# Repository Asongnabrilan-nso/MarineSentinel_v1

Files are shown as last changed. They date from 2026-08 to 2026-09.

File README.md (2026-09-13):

# 🌊 MarineSentinel

**A ~$300 floating AI sentinel that watches a river or coastline for plastic
pollution around the clock, and logs water quality — built on a single
Arduino UNO Q.**

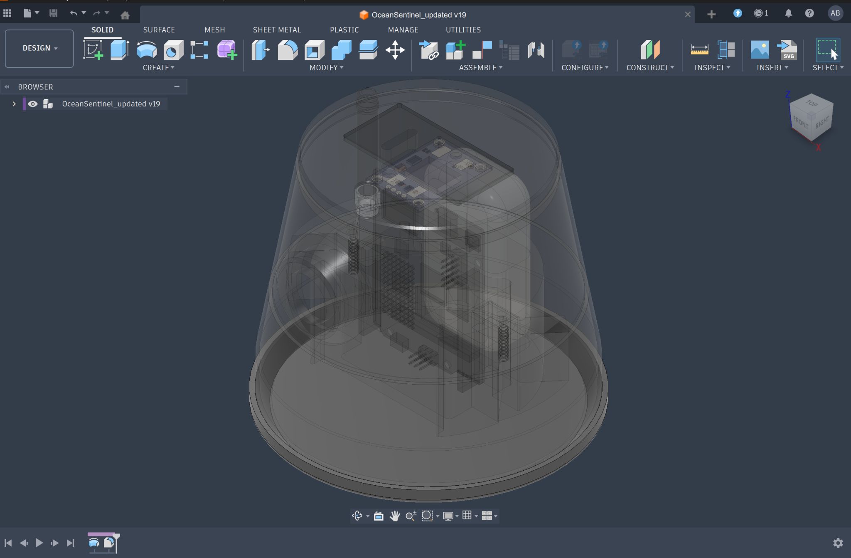
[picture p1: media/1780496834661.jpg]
MarineSentinel buoy — Fusion 360 cutaway render showing the sealed electronics stack inside the capsule


📖 Full project write-up (story + build photos):
[hackster.io/abrilannso/marinesentinel-60f927](https://www.hackster.io/abrilannso/marinesentinel-60f927)
&nbsp;·&nbsp; 🔧 Technical deep-dive:
[`firmware/README.md`](firmware/README.md)
&nbsp;·&nbsp; 👤 Built by
[Asongna Brilan Nso Nkengafac](https://www.hackster.io/abrilannso)

---

## Contents

1. [Overview](#overview)
2. [At a glance](#at-a-glance)
3. [How it works](#how-it-works)
4. [Bill of materials](#bill-of-materials)
5. [Build guide](#build-guide)
6. [Repository layout](#repository-layout)
7. [Troubleshooting](#troubleshooting)
8. [Conclusion](#conclusion)
9. [Credits](#credits)

---

## Overview

MarineSentinel started on a visit to Limbe Down Beach (Cameroon), watching
plastic wash in through the drains and inlets that feed the ocean — water
that local fishing communities depend on. Almost nobody measures any of this
continuously: pollution is recorded, if at all, by someone travelling to a
site to take one photo or one sample. A commercial multi-parameter water
sonde costs US$25,000–40,000, so no local municipality instruments a river,
and "we have no numbers" becomes the reason cleanup funding proposals fail.

MarineSentinel is a small sealed buoy that floats on the water and watches
it for you, day and night:

- A **camera + on-device AI model** learns what floating plastic and debris
  look like and flags it when it sees it.
- Onboard sensors continuously measure **turbidity**, **water temperature**,
  and the buoy's own **tilt/motion** from the waves.
- A **GPS fix** locates every reading and every alert.
- Everything is served live from a **web dashboard the buoy hosts itself**
  over WiFi — open it on a phone at the water's edge, no internet required.

It doesn't scoop up trash — it's the sensor layer for someone else's
cleanup: it tells a crew *where* and *when* debris is flowing, and warns
people who depend on the water the moment a reading looks wrong. Every part
is buyable locally within 48 hours, so a local workshop can rebuild or
repair it without waiting on an import.

## At a glance

| | |
|---|---|
| **Board** | Arduino UNO Q (STM32 MCU + Linux MPU on one board) |
| **Cost** | ~US$300 all-in, nothing imported |
| **Senses** | Turbidity · water temperature · tilt/orientation (IMU) · GPS |
| **AI** | On-camera debris detection — built-in YOLO-X or a custom Edge Impulse model |
| **Output** | Self-hosted live web dashboard (`http://<board-ip>:7000`), no internet needed |
| **Enclosure** | 3D-printed PETG, 5 snap-together parts, solar-trickle powered |

**Status — bench-proven and water-tested, end to end:**
- ✅ Live camera feed with on-device debris detection (YOLO-X / custom Edge Impulse model)
- ✅ Turbidity + temperature sampled every 2 s, with alert thresholds
- ✅ IMU-driven 3D tilt view at 10 Hz, with a capsize/listing alert
- ✅ GPS fix pushed to the dashboard at 1 Hz
- ✅ Sensor/orientation/detection history logged to on-device InfluxDB
- ✅ Camera and IMU startup are retry-safe — a missing sensor fails open instead of crashing the app

## How it works

The Arduino UNO Q carries two processors on one board, and MarineSentinel
gives each the job it's built for, passing messages between them over
[Arduino App Lab](https://docs.arduino.cc/software/app-lab/)'s **Router
Bridge**:

```
┌──────────────────────────────┐                     ┌──────────────────────────────────┐
│  MCU (Zephyr sketch)         │  Router Bridge:      │  MPU (Python / web_ui)            │
│  sketch/sketch.ino           │  sensor_data (2s)    │  python/main.py                    │
│                               │  imu_data (100ms)     │                                    │
│  A0      ── turbidity sensor │  gps_data (1s)          │  ├─ sensors.py (state + alerts)  │
│  D4      ── DS18B20 (1-Wire) │ ────────────────────────▶│  ├─ data_store.py (InfluxDB)     │
│  QWIIC   ── MPU6050 IMU      │                          │  ├─ assets/ (static HTML/JS —    │
│            (I2C4 = Wire1)    │  ◀────────────────────  │  │   CSS-3D capsule, no CDN)      │
│  D20/D21 ── GPS (Serial3)    │  set_alert(bool)      │  └─ VideoObjectDetection             │
│  LED3    ── alert indicator  │                     │        (YOLO-X / custom Edge Impulse) │
└──────────────────────────────┘                     └──────────────────┬─────────────────────┘
                                                                          │ :7000 (Socket.IO)
                                                                          ▼
                                                           Browser dashboard (LAN) — camera pane
                                                           and orientation view refresh at 10 Hz,
                                                           independent of the rest of the page
```

1. **The real-time microcontroller reads the world.** The sketch samples
   turbidity and a DS18B20 water-temperature probe every 2 s, fuses the
   MPU6050 accelerometer + gyroscope into roll/pitch/yaw at 10 Hz, parses
   GPS NMEA sentences continuously, and drives the onboard RGB LED
   green/red as a local alarm — all independent of whether Python is even
   listening.
2. **The Linux processor runs the AI and the dashboard.** An always-on
   Python process (`arduino:web_ui`) runs object detection on the USB
   camera feed, converts raw sensor values to engineering units, evaluates
   alert thresholds (including a capsize/listing check on tilt), writes
   history to an on-device InfluxDB, and serves a static dashboard.
3. **The two halves stay in sync over the bridge.** The sketch fires
   `sensor_data`, `imu_data`, and `gps_data` up to Python; Python sends
   `set_alert` back down to drive the LED.

Three App Lab bricks do the heavy lifting (declared in
[`firmware/app.yaml`](firmware/app.yaml)):

| Brick | Purpose |
|---|---|
| `arduino:video_object_detection` | Object detection (built-in YOLO-X, or a custom Edge Impulse export) on the USB camera stream |
| `arduino:web_ui` | Always-on Python process + the Socket.IO dashboard on port `7000` |
| `arduino:dbstorage_tsstore` | InfluxDB-backed time-series storage for sensor/orientation history |

<details>
<summary><strong>Why this needs two processors, and why <code>web_ui</code> instead of Streamlit</strong> (click to expand)</summary>

- **Two processors, one board.** The real-time MCU owns the sensors and
  electronics; the Linux side only carries the vision model and dashboard —
  no separate SBC + microcontroller pair to wire together.
- **App Lab bricks instead of hand-rolled services.** The camera model
  runner, the dashboard, the time-series database, and start-on-boot all
  arrive as declared components in `app.yaml`.
- **`web_ui`, not Streamlit.** Streamlit only executes app code the first
  time a browser opens the dashboard — on an unattended buoy deployment
  where nobody opens the dashboard, the Bridge providers, camera/AI
  detector, and InfluxDB storage would never start at all. `web_ui` is a
  plain always-on process: everything starts the instant the app boots,
  dashboard or not.
- **The 3D capsule tilt indicator** is drawn with plain CSS 3D transforms —
  no Three.js, no CDN — so it still renders for a browser that can only
  reach the buoy itself, out on the water with no path to anywhere else.
- **The repo mirrors the device.** [`firmware/`](firmware) is exactly the
  on-device app layout — what you clone is what runs.

See [`firmware/README.md`](firmware/README.md) for the full changelog and
the non-obvious bugs this surfaced along the way (I²C bus selection on the
QWIIC connector, Bridge/`App.run()` ordering, etc.).

</details>

## Bill of materials

Everything beyond the UNO Q itself came to roughly **157,506 XAF (~US$260)**,
sourced entirely locally — the whole build lands under $300 with no
import/customs step on the critical path.

| Component | Notes |
|---|---|
| Arduino UNO Q | the board — MPU + MCU |
| USB webcam (e.g. Logitech HD Pro) | debris-detection camera |
| MPU6050 6-DOF IMU (e.g. DFRobot breakout) | mounts on the QWIIC connector |
| DS18B20 waterproof temperature probe | 1-Wire, e.g. DFRobot Gravity |
| GPS receiver (e.g. Adafruit Ultimate GPS Breakout) | NMEA over `Serial3` |
| Turbidity sensor, phototransistor output | e.g. SEN0189-class module |
| Solar panel, 2.5 W + buck converter | trickle-charges the buoy in the field |
| Li-Ion battery, 1000 mAh | onboard power |
| PETG filament | for the 3D-printed enclosure |
| 2× M3 screws | the only fasteners — the enclosure snaps together |

## Build guide

Follow these in order. Steps 1–4 are mechanical/electrical and can be done
without the board powered on; steps 5–8 bring the firmware up.

### Step 1 — 3D-print the enclosure

Print the five parts from [`mechanical/stl/`](mechanical/stl) in PETG (STEP
source: `mechanical/stl/MarineSentinel.step`). They snap together with just
2× M3 screws — no glue.

| Part | Holds |
|---|---|
| **Buoy Cover** | solar panel, GPS antenna, charging/power electronics |
| **Buoy Mid Body** | the camera, for live footage |
| **Buoy Bottom** | the IMU and water-facing sensors |
| **Buoy Floating Base** | flotation (polythene foam) |
| **Electronics Enclosure** | the UNO Q, battery, and wiring |

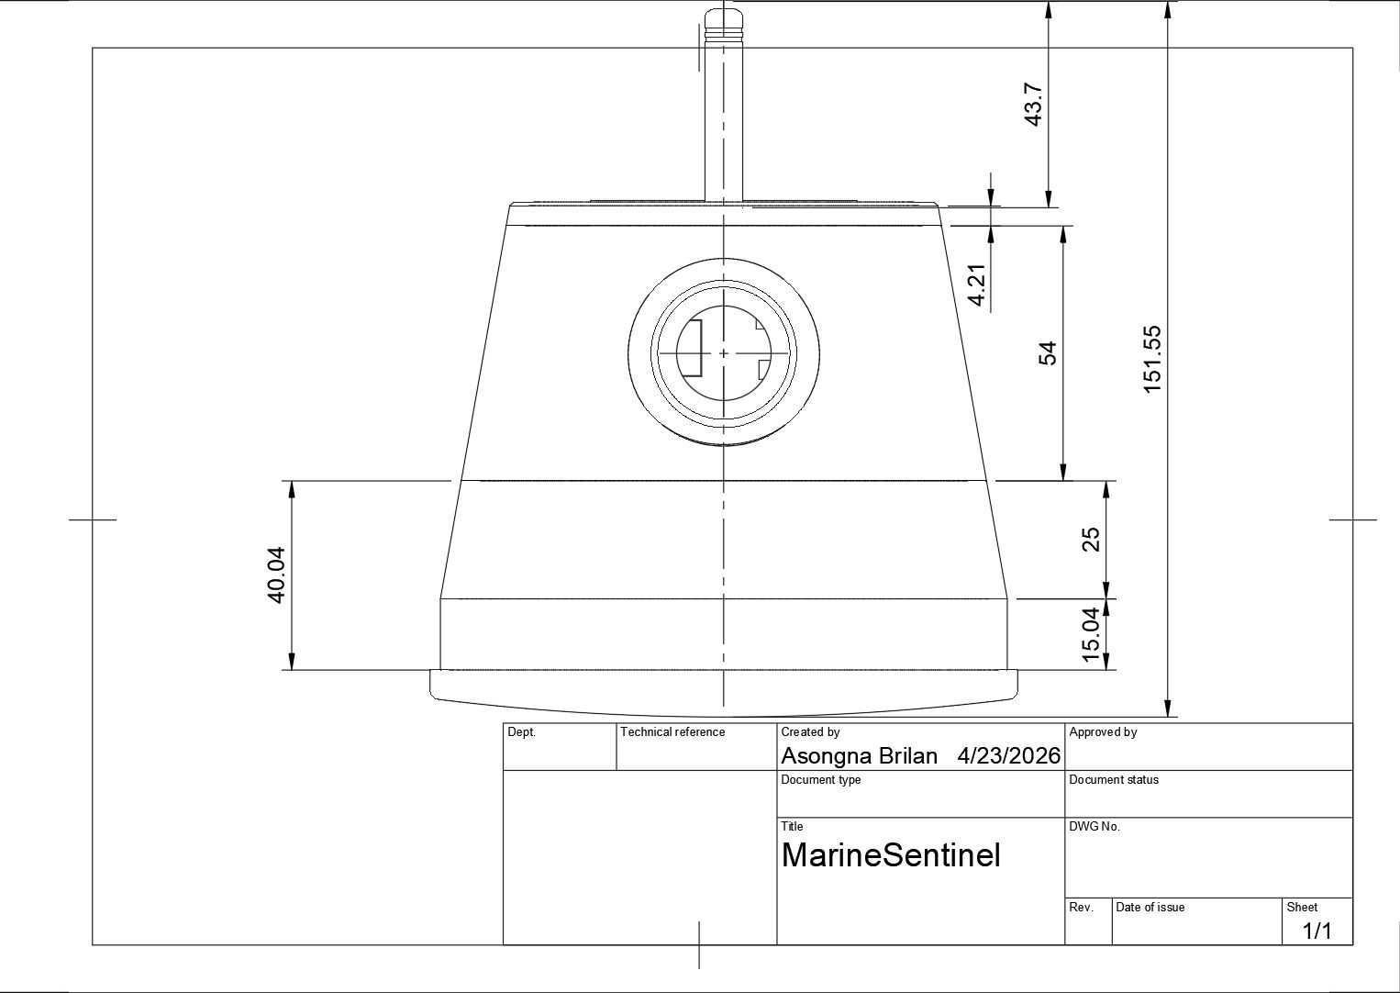
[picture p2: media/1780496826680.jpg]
Dimensioned CAD drawing of the buoy body


### Step 2 — Wire power and solar

Mount the 2.5 W solar panel and GPS antenna on the **Buoy Cover**'s top
side; mount the charging circuit, buck converter, and battery on its
underside.

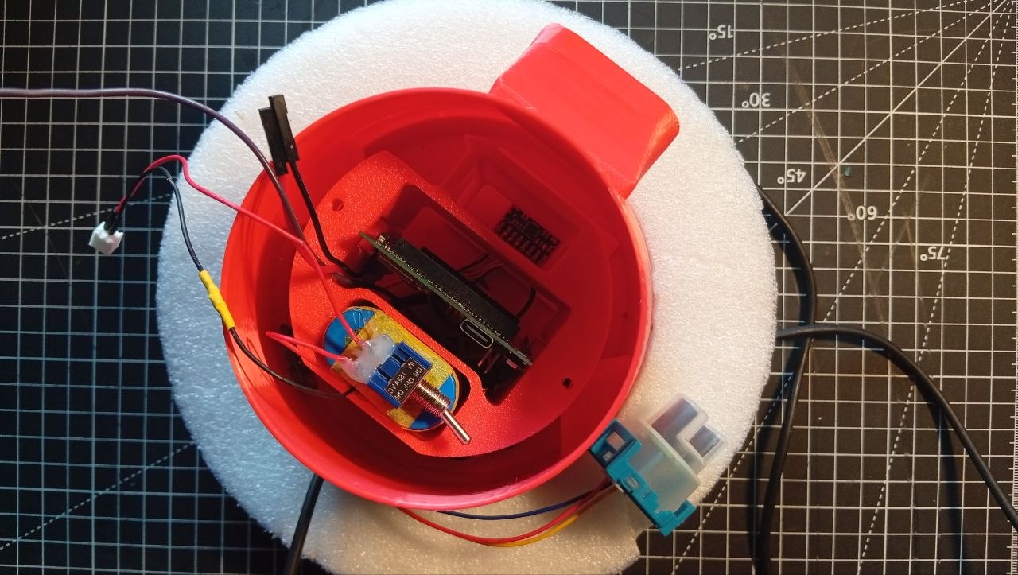
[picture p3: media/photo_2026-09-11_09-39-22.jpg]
Power and GPS electronics mounted in the buoy cover


### Step 3 — Mount electronics and sensor modules

1. Place the turbidity + temperature sensor module in the **Buoy Bottom**.
2. Seat the 7.4 V battery pack in the **Electronics Enclosure**.
3. Slide the UNO Q onto the guide rail, then close the enclosure over it.

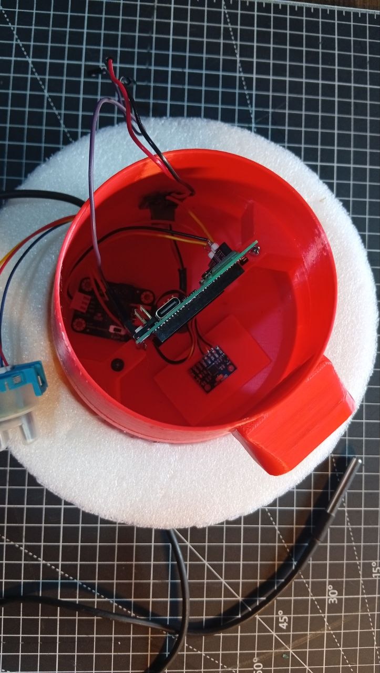
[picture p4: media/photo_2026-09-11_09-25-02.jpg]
Sensor module mounted in the buoy bottom


### Step 4 — Final assembly

Snap the Buoy Bottom, Mid Body, Cover, and Electronics Enclosure together
onto the Floating Base and drive in the two M3 screws. Double-check every
sensor cable is routed before closing the capsule — it's sealed once
assembled.

### Step 5 — (Optional) train a custom debris model in Edge Impulse

The built-in `arduino:video_object_detection` brick ships a general-purpose
YOLO-X model that already recognizes common floating objects. For
debris-specific detection instead:

1. Create a project on [Edge Impulse Studio](https://www.edgeimpulse.com/).
2. Collect and label photos (e.g. plastic bags, plastic bottles, open ocean
   water).
3. Train an object-detection model and export it via Edge Impulse's **App
   Lab export** — no manual model files or SDK calls to manage.

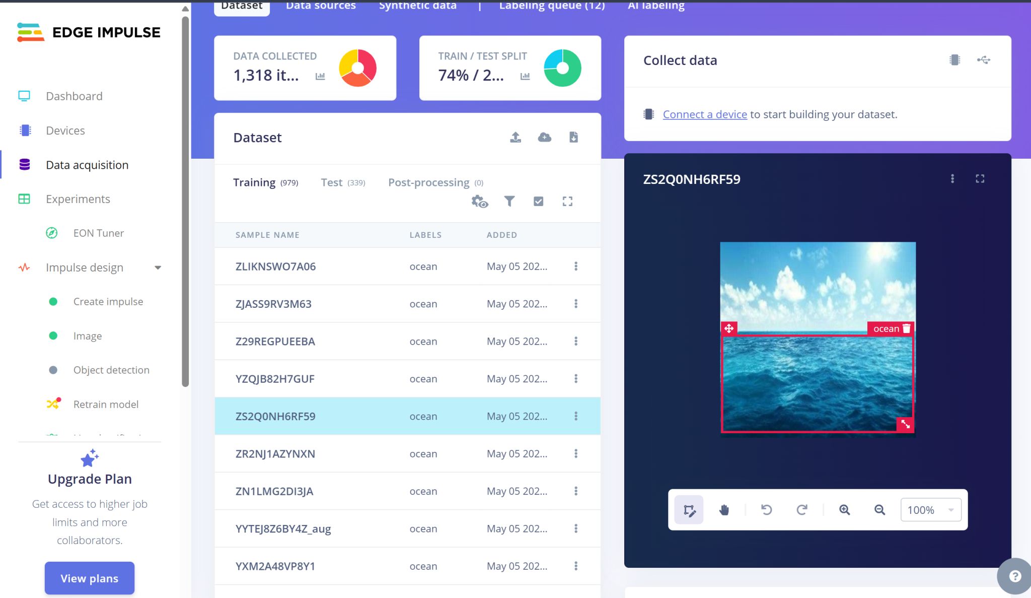
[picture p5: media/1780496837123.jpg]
Edge Impulse Studio dataset — labeled ocean water samples
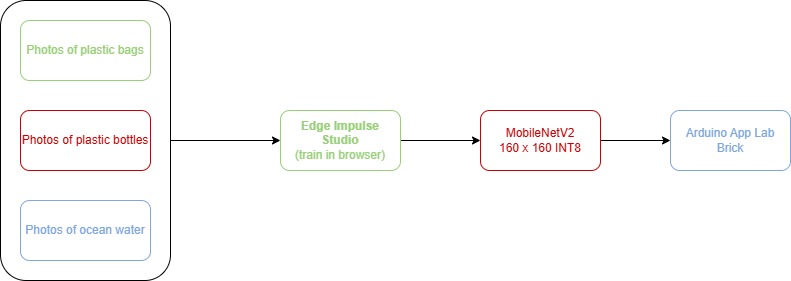
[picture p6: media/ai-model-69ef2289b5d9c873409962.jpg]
Custom model training pipeline: labeled photos through Edge Impulse Studio to a MobileNetV2 model deployed as an App Lab brick
 

### Step 6 — Install Arduino App Lab and set up the board

1. Install [Arduino App Lab](https://www.arduino.cc/en/software/).
2. Connect the UNO Q with a USB-C cable.
3. On first connection, App Lab prompts you to name the board, set a
   password, and join it to your WiFi (or a local hotspot) — do that.

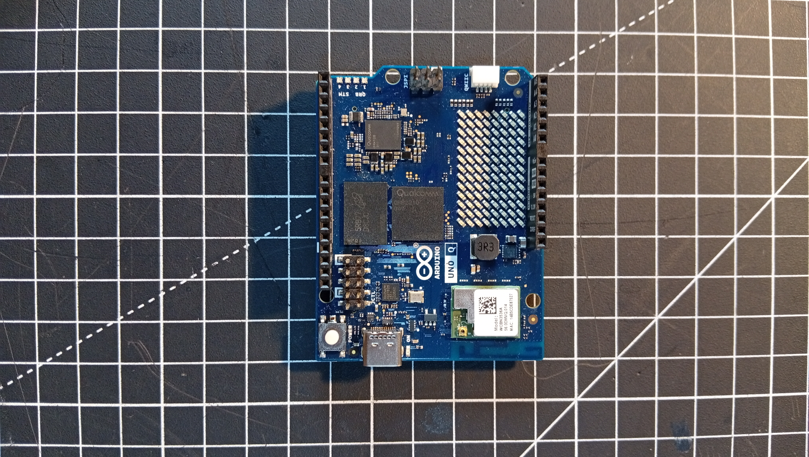
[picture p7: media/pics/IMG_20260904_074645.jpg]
Arduino UNO Q board
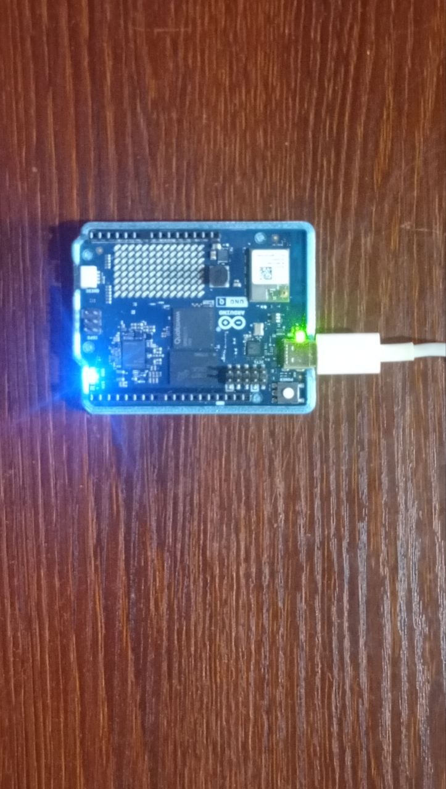
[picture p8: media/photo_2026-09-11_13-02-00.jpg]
Arduino UNO Q powered on via USB-C
 

### Step 7 — Clone and load the app

From the board's shell (SSH, or App Lab's built-in terminal) for full
control over the files:

```bash
git clone https://github.com/Asongnabrilan-nso/MarineSentinel_v1.git ~/ArduinoApps/MarineSentinel_v1
```

Open `~/ArduinoApps/MarineSentinel_v1/firmware` as the app in App Lab (or
just use the CLI directly — see Step 8).

### Step 8 — Point `app.yaml` at your model, then run it

If you trained a custom model in Step 5, register it and point the app at
it — otherwise skip straight to `app start` and the built-in YOLO-X model
is used:

```bash
arduino-app-cli model list          # confirm your Edge Impulse import shows up
```

```yaml
# firmware/app.yaml
bricks:
  - arduino:video_object_detection:
      model: ei-model-XXXXXX-N      # the ID from `model list`
```

Then build, flash, and launch everything in one command:

```bash
arduino-app-cli app start ~/ArduinoApps/MarineSentinel_v1/firmware
```

This compiles and flashes `sketch/sketch.ino` to the MCU, builds the Python
environment, and starts the dashboard + video-detection runner + InfluxDB.
First start takes a few minutes while dependencies download.

> ⚠️ `app start` **stops whatever app is currently running** on the board —
> only one App runs at a time.

Make sure the USB camera is plugged in (use a USB-C hub if the board's
port is occupied) before starting.

### Step 9 — Open the dashboard

From any device on the same WiFi/LAN as the board:

```
http://<board-ip>:7000
```

You should see live turbidity/temperature tiles, the orientation capsule
tracking the buoy's tilt, a live annotated camera feed, and a debris
detection log.

**Everyday commands, once it's running:**

```bash
arduino-app-cli app restart ~/ArduinoApps/MarineSentinel_v1/firmware      # apply code changes
arduino-app-cli app logs    ~/ArduinoApps/MarineSentinel_v1/firmware --follow   # Python logs
arduino-app-cli monitor                                                   # MCU Serial.print()
arduino-app-cli app stop    ~/ArduinoApps/MarineSentinel_v1/firmware
```

## Repository layout

```
MarineSentinel_v1/
├── firmware/               # the Arduino App — this is what you clone onto the board
│   ├── app.yaml             # manifest + brick declarations
│   ├── python/                # main.py, sensors.py, data_store.py
│   ├── sketch/                  # sketch.ino, sketch.yaml
│   ├── assets/                    # static dashboard (HTML/JS/CSS, Socket.IO)
│   └── README.md                    # full technical write-up, wiring, troubleshooting
├── mechanical/              # Fusion 360 STEP + STL files for the enclosure
├── media/                   # build/CAD/dashboard photos used in this README
└── marinesentinel_spec.json # project spec (requirements, BOM, timeline)
```

## Troubleshooting

Camera not found, IMU not detected, GPS stuck without a fix, dashboard
feeling stuck — the full troubleshooting table, wiring reference, and the
reasoning behind each fix live in
[`firmware/README.md` → §3.4 Troubleshooting](firmware/README.md#34-troubleshooting).

That file is also the place to look for:
- [Adding more sensors](firmware/README.md#5-adding-more-sensors) (worked
  example, e.g. a pH sensor)
- [Loading a different Edge AI model](firmware/README.md#4-loading-a-different-edge-ai-model-edge-impulse)
- The dated [changelog](firmware/README.md#7-changelog) of what changed and
  why

## Conclusion

MarineSentinel started from a simple frustration: the water that needed
watching the most was the water nobody could afford to watch. A
US$25,000–40,000 sonde was never going to sit in a river in Cameroon, so the
only way to get numbers was to build something that could.

What's in this repo is a buoy built almost entirely from parts on a local
bench — turbidity, temperature, tilt, GPS, and a camera with an AI model
that already knows what a plastic bottle looks like — running on one board,
reporting itself over a dashboard with no internet needed. It isn't a
finished monitoring network. It's proof that a $300, locally-sourced
instrument can do the job a $30,000 imported one was priced to do, and that
someone at the water's edge can read it on their phone.

It's also not a cleanup tool, and it doesn't pretend to be. MarineSentinel's
job stops at telling someone *where* the debris is and *when* the water
turns bad — the cleanup crew, the health warning, the funding case built on
real data instead of a single photo, that's for whoever picks up what it
reports.

**What's next:**

- **Longer deployments** — the current build is bench- and water-tested in
  short runs; the real test is weeks on the water unattended.
- **A magnetometer** — to fix the yaw drift (see
  [`firmware/README.md` §2.6](firmware/README.md#26-yaw-has-no-accelerometer-equivalent-correction--it-will-drift))
  and give the buoy a real compass heading, not just relative orientation.
- **More water-quality sensors** (pH, dissolved solids) — the sensor
  pipeline is built to make this a small, worked-example change, not a
  redesign (see
  [`firmware/README.md` §5](firmware/README.md#5-adding-more-sensors)).
- **More than one buoy** — a single sentinel gives you a point reading; a
  handful along a coastline gives you a map of where the pollution is
  actually coming from.

Every file, every model, every STL is in this repo. If the water near you
has the same problem — no data because no one can afford to collect it —
this is built to be cloned, not just read about.

## Credits

Built by [Asongna Brilan Nso Nkengafac](https://www.hackster.io/abrilannso).
Full project story, build log, and step-by-step assembly photos:
[hackster.io/abrilannso/marinesentinel-60f927](https://www.hackster.io/abrilannso/marinesentinel-60f927).

Source is licensed Mozilla Public License 2.0 (see SPDX headers in
`firmware/python/` and `firmware/sketch/`).

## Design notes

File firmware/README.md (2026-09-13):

# 🌊 MarineSentinel

Marine water quality monitoring for the Arduino UNO Q, combining real-time
sensor fusion (turbidity + temperature + orientation) on the MCU with Edge AI
debris detection and a live web dashboard on the MPU.

- **MCU (sketch)** — samples a turbidity sensor and a DS18B20 temperature
  probe every 2 s, fuses accel+gyro from an MPU6050 (QWIIC/I2C) into
  roll/pitch/yaw at 10 Hz, parses GPS NMEA sentences continuously and
  reports a fix at 1 Hz, streams all of it to the MPU over the Router
  Bridge, and drives an onboard RGB LED (green/red) as a local alert
  indicator.
- **MPU (Python)** — receives sensor + orientation + GPS readings, converts
  them to engineering units, evaluates alert thresholds (including a
  capsize/tilt check), stores history in InfluxDB, runs YOLO-X (or a custom
  Edge Impulse) object detection on a USB camera feed to spot floating
  debris, and publishes everything — including a live 3D capsule
  orientation view — to a static HTML/JS dashboard served over Socket.IO on
  port `7000`.

---

## 1. Architecture

```
┌──────────────────────────────┐                     ┌──────────────────────────────────┐
│  MCU (Zephyr sketch)         │  Router Bridge:      │  MPU (Python / web_ui)            │
│  sketch/sketch.ino           │  sensor_data (2s)    │  python/main.py                    │
│                               │  imu_data (100ms)     │                                    │
│  A0      ── turbidity sensor │  gps_data (1s)          │  ├─ sensors.py (state + alerts)  │
│  D4      ── DS18B20 (1-Wire) │ ────────────────────────▶│  ├─ data_store.py (InfluxDB)     │
│  QWIIC   ── MPU6050 IMU      │                          │  ├─ assets/ (static HTML/JS —    │
│            (I2C4 = Wire1)    │  ◀────────────────────  │  │   CSS-3D capsule, no CDN)      │
│  D20/D21 ── GPS (Serial3)    │  set_alert(bool)      │  └─ VideoObjectDetection             │
│  LED3    ── alert indicator  │                     │        (YOLO-X / custom Edge Impulse) │
└──────────────────────────────┘                     └──────────────────┬─────────────────────┘
                                                                          │ :7000 (Socket.IO)
                                                                          ▼
                                                           Browser dashboard (LAN) — camera pane
                                                           and orientation view refresh at 10 Hz,
                                                           independent of the rest of the page
```

Bricks used (`app.yaml`):

| Brick | Purpose |
|---|---|
| `arduino:video_object_detection` | Runs the object-detection model (built-in YOLO-X, or a custom Edge Impulse export) against the USB camera stream |
| `arduino:web_ui` | Hosts the always-on Python process and the static Socket.IO dashboard on port 7000 |
| `arduino:dbstorage_tsstore` | InfluxDB-backed time series storage for sensor history |

> **Note:** this app originally ran on `arduino:streamlit_ui`. It was
> rewritten onto `arduino:web_ui` because Streamlit only executes app code
> the first time a browser opens the dashboard — on an unattended buoy
> deployment where nobody opens the dashboard, the Bridge providers, camera/
> AI detector, and InfluxDB storage would never start at all. `web_ui` is a
> plain always-on process: everything below `App.run()` starts the instant
> the app boots, dashboard or not. Sections 2.1–2.9 below predate this
> rewrite and describe Streamlit-era bugs that no longer apply to the
> current `assets/`-based dashboard; kept for historical record.

---

## 2. Challenges & solutions

Building the Python side surfaced a few non-obvious issues — recorded here
so they aren't rediscovered the hard way.

### 2.1 `Logger.info(...)` crashed the app on boot
`arduino.app_utils.Logger` is a `logging.Logger` subclass meant to be
**instantiated** (`logger = Logger("MyApp")`), not called as a static
method. The original code called `Logger.info("...")` directly on the
class, which Python interprets as `Logger.info(self="...")` — missing the
required `msg` argument, raising `TypeError` and crashing the whole
Streamlit script before anything rendered.

**Fix:** instantiate one module-level logger per file
(`logger = Logger("MarineSentinel")`) and call `logger.info(...)` on the
instance.

### 2.2 `App.run()` was placed after `st.rerun()` — bricks never started
The dashboard auto-refreshes every 3 s with `time.sleep(3); st.rerun()`.
`st.rerun()` aborts the running script immediately (it's a Streamlit
control-flow exception, not a normal return) — so any code placed after it
**never executes**. `App.run()` was the last line of the file, after the
`st.rerun()` call.

This matters because `AppController` (the object behind `App`) only starts
a brick's background threads — the video detector's WebSocket connection to
the model runner and its camera→runner TCP forwarding loop — inside
`App.run()`. With `App.run()` unreachable, the camera opened fine (it's
started explicitly via `detector.start()`), but no frames or detections
ever made it back to Python: the WebSocket never connected, and
`on_detect_all()` never fired.

**Fix:** call `App.run()` immediately after brick initialization, *before*
the dashboard layout and the auto-refresh `st.rerun()`. This is safe on
every re-run: in Streamlit's "framework-managed" mode `App.run()` is
idempotent and returns immediately instead of blocking — it only actually
starts brick threads on the first call.

### 2.3 Detection payload shape didn't match what the code assumed
`VideoObjectDetection.on_detect_all()`'s docstring says the callback
receives `{label: confidence}`, but the installed brick source
(`arduino/app_bricks/video_objectdetection/__init__.py`) actually builds
`{label: [{"confidence": ..., "bounding_box_xyxy": ...}, ...]}` — a list of
detections per label, since a frame can contain multiple instances of the
same class. Code written against the docstring's shape crashes or silently
misbehaves (e.g. `f"{confidence:.0%}"` on a list).

**Fix:** `sensors.summarize_detections()` reduces the raw
`{label: [box, ...]}` payload to `{label: best_confidence}` for display,
while debris logging still works off the normalized summary.

### 2.4 The live camera feed only updates when something is detected
By design, `on_detect_all()` (and the frame it passes) only fires when the
model finds an object above the confidence threshold — there's no public
"give me every frame" callback. That's fine for event logging, but a
"live camera" section that freezes on the last detected object isn't
actually live.

**Fix:** the detector keeps a continuously-updated raw preview frame
internally (`detector._last_camera_frame`, refreshed by the model runner on
every cycle). `main.py` reads that directly as a fallback so the feed stays
live between detections, and swaps in the bounding-box-annotated frame for
a few seconds right after a detection fires. This touches a private
attribute, not public API — if a future SDK version renames it, the code
fails closed (`try/except` → falls back to "Waiting for camera feed…"),
it doesn't crash the dashboard.

### 2.5 Orientation: feed the complementary filter fast, report it slow
The MPU6050 doesn't output an angle directly — `MPU6050_light`'s fused
roll/pitch come from a complementary filter that blends gyro integration
(`angle += gyroRate * dt`) with the accelerometer's tilt estimate on every
call to `update()`. The turbidity/temperature loop only samples every 2 s,
so calling `imu.update()` on that same coarse cadence would feed the filter
a 2-second `dt` — the single-step gyro integration term would dominate the
fused angle and only get pulled back toward the (correct) accelerometer
reading by a small filter coefficient each time, making roll/pitch sluggish
and inaccurate.

**Fix:** `sketch.ino`'s `loop()` calls `imu.update()` on *every* tick
(sub-millisecond `dt`, accurate fusion) but only sends the result over the
Bridge every `IMU_SEND_INTERVAL_MS` (10 Hz) via a separate `lastImuSendMs`
timer — decoupling the filter's internal update rate from how often Python
actually needs a fresh reading. Turbidity/temperature sampling keeps its own
independent 2 s timer, unchanged.

### 2.5b The QWIIC connector is a *different* I2C bus than plain `Wire`
The MPU6050 was correctly wired to the board's QWIIC connector, powered, and
still got a hard I2C failure — `Wire.begin(); imu.begin()` returned status 1
(NACK), and a full 1–127 address bus scan found **nothing at all**. The
board's official pinout PDF and the ArduinoCore-zephyr devicetree overlay
(`arduino_uno_q_stm32u585xx.overlay`) explain why:

```
zephyr,user { i2cs = <&i2c2>, <&i2c4>, <&i2c3>; ... };
```

`Wire.h` declares one `arduino::ZephyrI2C` object per entry in that list, in
order — so plain `Wire` is **I2C2** (the digital header's D20/D21 pins),
`Wire1` is **I2C4**, and `Wire2` is **I2C3** (the analog header's A4/A5
pins). The pinout diagram confirms the QWIIC connector's SDA/SCL pins
(`PD13`/`PD12`) are wired to I2C4 — i.e. **`Wire1`**, not the default `Wire`.
Two electrically separate I2C buses meant the scan on `Wire` legitimately
found nothing; the MPU6050 was never on that bus to begin with.

**Fix:** `MPU6050 imu(Wire1)` and `Wire1.begin()` instead of `Wire`. If you
move the MPU6050 to the analog header's I2C3 pins instead, it's `Wire2`; the
plain header-adjacent `Wire` is I2C2 (D20/D21), not exposed via any labeled
connector on this board's default configuration.

### 2.6 Yaw has no accelerometer-equivalent correction — it will drift
Roll and pitch are self-correcting: the accelerometer's gravity-vector tilt
estimate continuously pulls the gyro-integrated angle back toward truth, so
they stay accurate indefinitely. Yaw (heading) has no such reference on a
plain MPU6050 (no magnetometer) — `getAngleZ()` is pure gyro integration and
accumulates drift for as long as the capsule runs.

**Fix:** this is disclosed, not "fixed" — the dashboard labels the Yaw
metric "drifts w/o magnetometer" and `sensors.normalize_yaw()` just wraps
the value into `[-180, 180)` for readability. Treat yaw as relative heading
since boot, not an absolute compass bearing. Adding an AK8963/QMC5883L
magnetometer (or an MPU9250) and fusing it in would fix this properly.

### 2.7 A 3D dashboard widget still has to work with no internet
The orientation view needed *some* 3D rendering to show the capsule's
attitude, but the capsule is meant to be deployed far from shore with only a
LAN link to the board — a widget that pulls three.js or any other library
from a CDN would show a blank box the moment a viewer's browser has no
internet path to that CDN, which defeats the point of a status dashboard.

**Fix:** `orientation_view.py` renders the capsule as a plain CSS 3D
transform (`rotateX/Y/Z` on a `<div>` built from six `position:absolute`
faces) via `st.components.v1.html` — no `<script src>`, no fonts, no
network calls of any kind. It's a cruder cube-and-labels capsule rather than
a shaded 3D mesh, but it keeps rendering correctly for a browser that only
ever reaches the board itself.

### 2.8 A 3 s full-page rerun makes 10 Hz data feel frozen
Sending orientation at 10 Hz over the Bridge didn't make the dashboard feel
any faster — because the whole page only ever redrew on the shared
`time.sleep(3); st.rerun()` cycle at the bottom of the script. The camera
and orientation section could be showing a value up to 3 s old no matter how
fast the MCU or the video model produced fresh data; the bottleneck was
entirely in how often the *page* re-rendered, not how often new data
arrived.

**Fix:** wrapped the Live Camera + Orientation section in
`@st.fragment(run_every=0.1)`. A fragment auto-reruns *only itself* on its
own schedule, without re-running or re-fetching the rest of the page (top
metrics, sensor history charts, debris log) — so this section now redraws
independently at 10 Hz, matching the MCU's `IMU_SEND_INTERVAL_MS`. One
subtlety: a fragment's own reruns don't re-execute code *outside* it, so it
must take its own fresh `state.snapshot()` rather than reusing a `snap`
computed once at the top of the full script.

### 2.9 Streamlit's re-run model requires strict init/render separation
Streamlit re-executes the whole script top-to-bottom on every interaction
and on every auto-refresh. Anything that opens hardware (camera, Bridge
handlers, DB connections) must be wrapped in `@st.cache_resource` so it
runs exactly once per process — otherwise every 3-second refresh would try
to reopen the USB camera and re-register Bridge handlers. `_init_system()`
in `main.py` is the single place this happens; everything below it is
pure render code safe to re-run.

---

## 3. Setup

### 3.1 Hardware

| Sensor | Pin | Notes |
|---|---|---|
| Turbidity (e.g. SEN0189, analog) | `A0` | 3.3 V ref, 10-bit ADC, oversampled ×8 |
| DS18B20 temperature probe (1-Wire) | `D2` | needs a 4.7 kΩ pull-up between data and 3.3 V if not already on the module |
| MPU6050 IMU (accel + gyro) | **QWIIC connector** (`Wire1` = I2C4 — see §2.5b, *not* plain `Wire`) | default address `0x68` (`AD0` low); mount the breakout flat with its silkscreen **X-axis arrow pointing toward the bow** — the sketch reads `getAngleX()`/`getAngleY()`/`getAngleZ()` as roll/pitch/yaw assuming that mounting |
| GPS module (NMEA, e.g. Adafruit Ultimate GPS) | `D20` (RX) / `D21` (TX) — **`Serial3`**, fixed by the board's devicetree pin muxing | wire GPS TX → D20, GPS RX → D21; reports fix/lat/lon/speed/course/satellites at 1 Hz once it has a lock |
| USB camera | any USB-A port (use a USB-C hub if needed) | required for object detection |
| Alert LED | onboard `LED3_R` / `LED3_G` (RGB, MCU-controllable) | green = OK, red = ALERT |

### 3.2 First run

```bash
# From the board (SSH / App Lab terminal):
arduino-app-cli app start ~/ArduinoApps/marine-sentinel
```

This compiles and flashes `sketch/sketch.ino` to the MCU, then builds the
Python virtualenv and starts the Streamlit UI + video detection runner +
InfluxDB containers. First start takes a few minutes (Streamlit,
pandas, numpy, pyarrow etc. get downloaded into `.cache/.venv`).

Open the dashboard from any device on the same LAN:

```
http://<board-ip>:7000
```

### 3.3 Everyday commands

```bash
arduino-app-cli app restart ~/ArduinoApps/marine-sentinel      # apply code changes
arduino-app-cli app logs    ~/ArduinoApps/marine-sentinel --follow   # Python/Streamlit logs
arduino-app-cli monitor                                        # MCU Serial.print() output
arduino-app-cli app stop    ~/ArduinoApps/marine-sentinel
```

`app start`/`app restart` **stop whatever app is currently running** on the
board — only one app runs at a time.

### 3.4 Troubleshooting

- **"No available cameras found"** on restart — the previous process
  hadn't released `/dev/video0` yet (docker container teardown race).
  Wait a few seconds and restart again; check `fuser -v /dev/video0` to see
  who currently holds it.
- **Dashboard shows `-- °C` / "Sensor Error"** — DS18B20 returns `-127.00`
  when it can't be read (not wired, no pull-up, or wrong pin). `temp_label()`
  in `sensors.py` maps anything `< -100` to "Sensor Error".
- **"Waiting for camera feed…" forever** — check
  `arduino-app-cli app logs ... | grep VideoObjectDetection` for a line
  reading `WebSocket connection established`. If it's missing, `App.run()`
  likely isn't being reached (see §2.2) or the `ei-video-obj-detection-runner`
  container isn't healthy (`docker ps`).
- **Orientation stuck at 0.0° / 0.0° / 0.0°** — no serial monitor needed:
  `arduino-app-cli app logs` prints `MPU6050: init FAILED, status=N — ...`
  repeatedly (every `IMU_SEND_INTERVAL_MS`, currently 100 ms) while the IMU
  isn't initialized, including the result of an I2C bus scan. If the scan
  found **nothing** (`scan_addr=0`), double check
  power and the QWIIC cable seating first, then confirm the sketch is
  actually using **`Wire1`** (the QWIIC connector is I2C4, a different bus
  than plain `Wire`/I2C2 — see §2.5b) — this was the actual root cause the
  first time around. If the scan found a device at `0x69`, AD0 is tied HIGH;
  either tie it low or call `imu.setAddress(0x69)`. The sketch fails open:
  turbidity/temperature keep working normally either way, orientation just
  stays unreported (`imuReady` stays `false`, no `imu_data` is sent).
- **Camera/orientation feel laggy or stuck for a few seconds** — see §2.8.
  Confirm `_live_panel()` in `main.py` is still decorated with
  `@st.fragment(run_every=...)` — without it, this section falls back to the
  slower shared 3 s full-page refresh.
- **Roll/Pitch look plausible but Yaw drifts over minutes** — expected, see
  §2.6. The MPU6050 has no magnetometer, so heading is gyro-integration only.

---

## 4. Loading a different Edge AI model (Edge Impulse)

The object-detection brick supports both Arduino's built-in models and
custom models trained on [Edge Impulse](https://edgeimpulse.com).

1. **Train & export on Edge Impulse Studio.** Build an object detection
   project, then export/deploy it as a Linux **`.eim`** model targeting the
   board's platform (UNO Q / imola).
2. **Import the model onto the board.** Upload it through App Lab's model
   manager (or place the exported files under
   `/home/arduino/.arduino-bricks/ei-models`, the path the brick reads from
   — see `CUSTOM_MODEL_PATH` in the brick's `brick_config.yaml`).
3. **Confirm it's registered:**
   ```bash
   arduino-app-cli model list
   ```
   Custom Edge Impulse imports show up as `ei-model-<id>-<n>` alongside the
   built-ins (`yolox-object-detection`, `face-detection`, ...).
4. **Point `app.yaml` at it:**
   ```yaml
   bricks:
     - arduino:video_object_detection:
         model: ei-model-XXXXXX-N     # the ID from `model list`
   ```
5. **Update the debris/classification logic.** `sensors.DEBRIS_CLASSES` is
   hardcoded to the COCO labels the current YOLO-X model can output
   (`bottle`, `cup`, `bowl`, ...). A custom model will emit **its own**
   label set — update `DEBRIS_CLASSES` (or replace the whole `is_debris()`
   check) to match the new model's classes, otherwise nothing will ever log
   as debris even if detections are firing correctly.
6. **Restart:** `arduino-app-cli app restart ~/ArduinoApps/marine-sentinel`.

---

## 5. Adding more sensors

The turbidity + temperature pair follows a repeatable pattern; a new sensor
means touching four places. Worked example — adding a pH sensor on `A1`:

1. **`sketch/sketch.ino`** — read the new pin in `loop()` and add it to the
   existing `Bridge.notify()` call (or send a separate notify if it's on a
   different cadence):
   ```cpp
   #define PH_PIN A1
   ...
   int phRaw = analogRead(PH_PIN);
   Bridge.notify("sensor_data", turbidityRaw, tempC, phRaw);
   ```
   If the sensor needs a library (I²C, extra driver, ...), declare it under
   `sketch/sketch.yaml` → `libraries:` with a pinned version — there's no
   separate "install" step, the build profile is the source of truth.

2. **`python/main.py`** — extend `_on_sensor_data`'s signature to match the
   new `Bridge.notify()` arity (positional args must line up):
   ```python
   def _on_sensor_data(turbidity_raw: int, temp_c: float, ph_raw: int):
       ph = raw_to_ph(ph_raw)          # add the conversion in sensors.py
       state.update_sensors(ntu, temp_c, ph)
   ```

3. **`python/sensors.py`** — add the raw→engineering-units conversion
   (mirroring `raw_to_ntu()`), an alert threshold if relevant, and extend
   `SensorState`/`update_sensors()`/`snapshot()` to carry the new field and
   its history deque.

4. **`python/main.py` (dashboard section)** — add a `st.metric(...)` in the
   top row and a `st.line_chart(...)` in the Sensor History column, same
   shape as the existing turbidity/temperature ones. Optionally call
   `store.record(...)` with the new field name so it lands in InfluxDB too
   (`data_store.py` → add a `FIELD_PH = "ph"` constant and pass it through
   `record()`).

Then `arduino-app-cli app clean-cache user:marine-sentinel --force` if the
sketch build looks stale, and `arduino-app-cli app restart ...`.

---

## 6. Project layout

```
marine-sentinel/
├── app.yaml              # manifest + brick declarations
├── python/
│   ├── main.py            # web_ui backend + Bridge/AI wiring (entry point)
│   ├── sensors.py          # unit conversion, alert rules, shared thread-safe state
│   └── data_store.py       # InfluxDB (TimeSeriesStore) wrapper
├── sketch/
│   ├── sketch.ino          # MCU: sensor + IMU + GPS sampling, LED alert, Bridge
│   └── sketch.yaml         # MCU build profile + library versions
├── assets/                # static dashboard: index.html, app.js, style.css
│                           # (CSS-3D capsule widget, no CDN/JS deps, pushed
│                           #  live updates over Socket.IO)
└── README.md
```

---

## 7. Changelog

Keep this section updated with dated entries as the project evolves —
newest first.

### 2026-09-11
- Added GPS: `sketch.ino` now reads NMEA sentences from a GPS module over
  `Serial3` (fixed to `D20`/`D21` by the board's pin muxing — not the usual
  `D11`/`D12` and no `SoftwareSerial` available on this Zephyr core) via
  `TinyGPSPlus`, and reports fix/lat/lon/speed/course/satellite-count to
  Python once a second over a new `gps_data` Bridge message. Surfaced live
  on the dashboard alongside the water-quality and orientation tiles.
- Rewrote the Python app from `arduino:streamlit_ui` onto `arduino:web_ui`:
  Streamlit only runs app code the first time a browser opens the dashboard,
  which meant an unattended buoy deployment — where nobody opens the
  dashboard — never started the Bridge providers, camera/AI detector, or
  InfluxDB storage at all. `web_ui` is a plain always-on process, so
  everything starts at boot regardless of whether a browser ever connects.
  The dashboard itself moved from Streamlit fragments to a static HTML/JS
  page (`assets/`) pushed live updates over Socket.IO — the CSS-3D capsule
  widget, camera pane, and metrics all carried over, just re-plumbed.
- Made camera/detector startup retry-safe: `VideoObjectDetection.start()`
  raising `CameraOpenError` (USB camera unplugged/busy/still enumerating) no
  longer kills the whole Python process — it retries in the background every
  10 s while the dashboard, sensors, and storage keep running.
- Verified on-device: `app logs` shows `gps_data` messages arriving at 1 Hz
  once the module has a fix, and the dashboard, sensors, and camera all come
  up on boot without a browser ever connecting to the app.

### 2026-09-03 (2)
- Fixed the MPU6050 not being detected at all: the QWIIC connector on the
  UNO Q is wired to a separate I2C peripheral (**I2C4 = `Wire1`**, devicetree
  order `i2cs = <&i2c2>, <&i2c4>, <&i2c3>` → `Wire`=I2C2, `Wire1`=I2C4,
  `Wire2`=I2C3), not the plain default `Wire` (I2C2, digital pins D20/D21)
  the sketch originally opened. `sketch.ino` now uses `Wire1` throughout.
- Added an I2C bus scan (`scanI2CBus()`) that runs whenever `imu.begin()`
  fails, and a Bridge `imu_status` message (repeated on the same
  `IMU_SEND_INTERVAL_MS` timer as `imu_data` while failed, to survive the
  Python-side handler registering after MCU boot) so a wiring problem shows
  up in `app logs` without needing a working serial monitor.
- Fixed both the live camera feed and the orientation view feeling stuck:
  the whole dashboard previously only redrew on the shared
  `time.sleep(3); st.rerun()` cycle, so a value could be up to 3 s stale.
  Moved both into an `st.fragment(run_every=...)` block, which auto-reruns
  *only* that section on its own schedule without re-running the rest of
  the page.
- Tuned for responsiveness: MCU `IMU_SEND_INTERVAL_MS` 1000→100 (10 Hz) and
  the dashboard fragment's `run_every` 1→0.1 (10 Hz) to match — going faster
  on one side without the other just re-renders/re-sends the same value.
- Verified on-device: `app logs` shows `MPU6050: found and calibrated —
  orientation streaming` after the `Wire1` fix, and `IMU: roll=... pitch=...
  yaw=...` lines arriving roughly every 100 ms. Confirmed live in the
  browser by the user.

### 2026-09-03
- Added MPU6050 orientation sensing: `sketch.ino` now fuses accel+gyro via
  `MPU6050_light` into roll/pitch/yaw and streams it to Python once a second
  over a new `imu_data` Bridge message, decoupled from the existing
  turbidity/temperature 2 s loop (§2.5).
- Added a "🧭 Orientation" dashboard section: a dependency-free CSS-3D
  capsule model (`orientation_view.py`, `st.components.v1.html`, no CDN/JS
  libraries — §2.7) plus Roll/Pitch/Yaw metrics and a tilt-history chart.
- Added a capsize/listing alert (`sensors.TILT_WARN_DEG` /
  `TILT_CRITICAL_DEG`) that merges into the existing alert feed and LED
  indicator alongside the turbidity/temperature alerts.
- Orientation history is persisted to InfluxDB (`data_store.record_orientation`)
  the same way turbidity/temperature already are.
- Yaw is gyro-integration only (no magnetometer) and will drift over a long
  deployment — disclosed on the dashboard and in §2.6 rather than "fixed".
- Verified on-device: `arduino-app-cli app start` compiled and flashed the
  sketch cleanly with the new `MPU6050_light` dependency; the Python changes
  were syntax- and logic-checked inside the app's actual running container
  (`sensors.py`/`orientation_view.py` unit-exercised, `main.py` compiles
  clean, `st.components.v1.html` confirmed present in the installed
  Streamlit 1.63.0). The live dashboard render (3D capsule responding to a
  physical tilt) was **not** visually confirmed in a browser this session —
  no browser-automation tool was available. Please open
  `http://<board-ip>:7000`, tilt the capsule, and confirm the capsule model
  and Roll/Pitch/Yaw track it before relying on this in the field.

### 2026-09-02
- Fixed `Logger.info(...)` being called as a static method, which crashed
  the app on every boot (§2.1).
- Fixed `App.run()` being placed after the auto-refresh `st.rerun()`,
  which silently prevented the video detector's WebSocket and camera
  threads from ever starting (§2.2).
- Fixed detection payload parsing: `sensors.summarize_detections()` now
  correctly handles the brick's real `{label: [box, ...]}` shape instead
  of the docstring's simplified `{label: confidence}` (§2.3).
- Added the "📷 Live Camera — Edge AI Monitoring" dashboard section:
  annotated (bounding-box) frames on detection, falling back to a
  continuously-updated raw preview between detections (§2.4).
- Enabled `camera_preview=True` on `VideoObjectDetection` and draw
  bounding boxes via `arduino.app_utils.image.draw_bounding_boxes`.
- Replaced deprecated `use_container_width=True` with `width='stretch'`
  (Streamlit 1.63 removes it after 2025-12-31).
- Verified end-to-end on-device: Bridge sensor stream, InfluxDB writes,
  live camera feed, and object detection ("person", "laptop" recognized
  at >45% confidence) all confirmed working via the running dashboard.

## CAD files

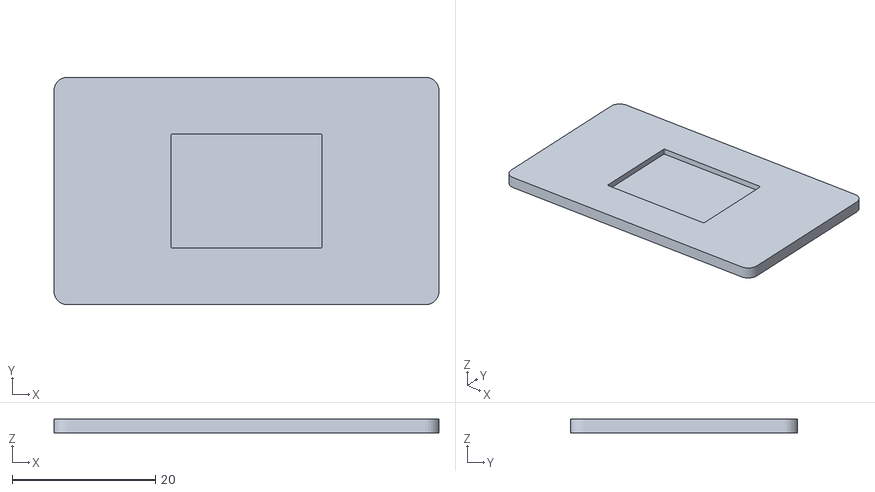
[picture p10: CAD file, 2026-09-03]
mechanical/stl/Body6.stl
53.7 x 31.7 x 2.00

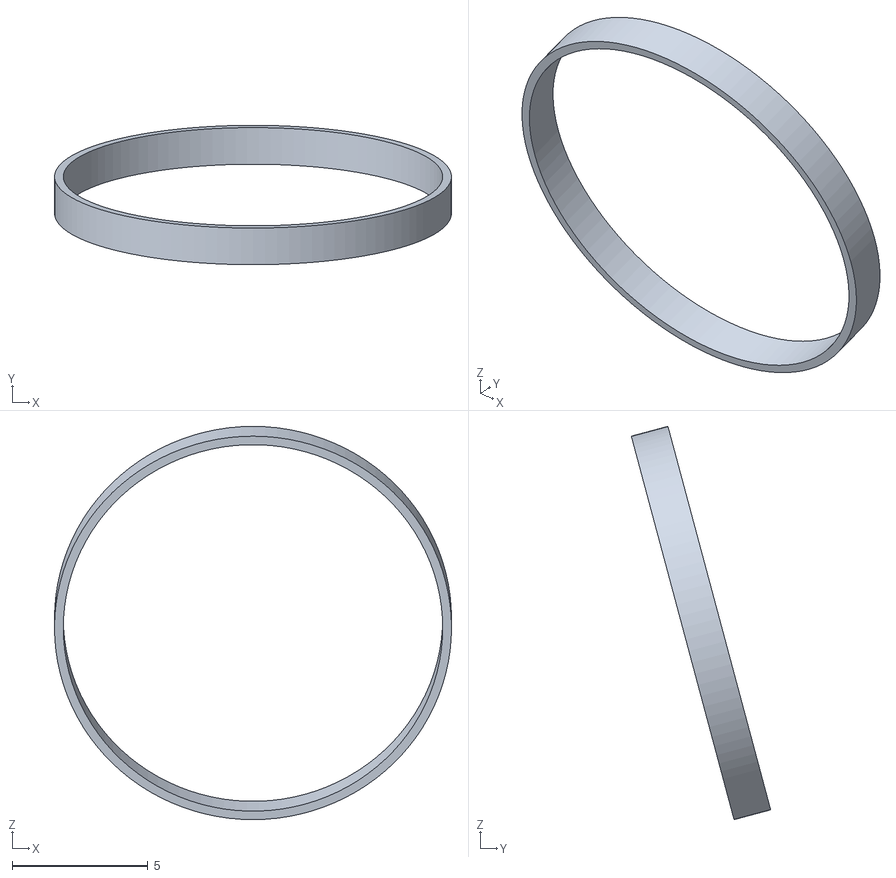
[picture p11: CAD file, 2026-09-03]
mechanical/stl/Camera ring tightener.stl
14.7 x 5.14 x 14.5

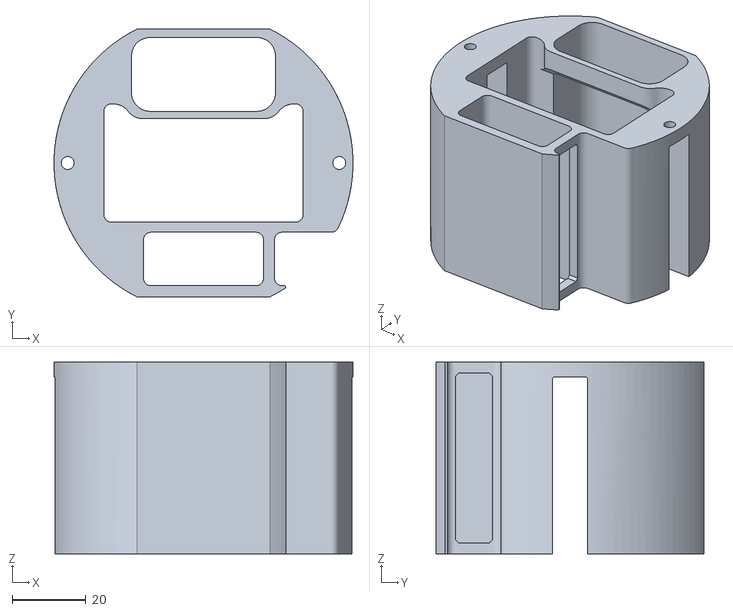
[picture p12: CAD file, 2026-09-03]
mechanical/stl/electronics Case.stl
81.0 x 72.5 x 52.0

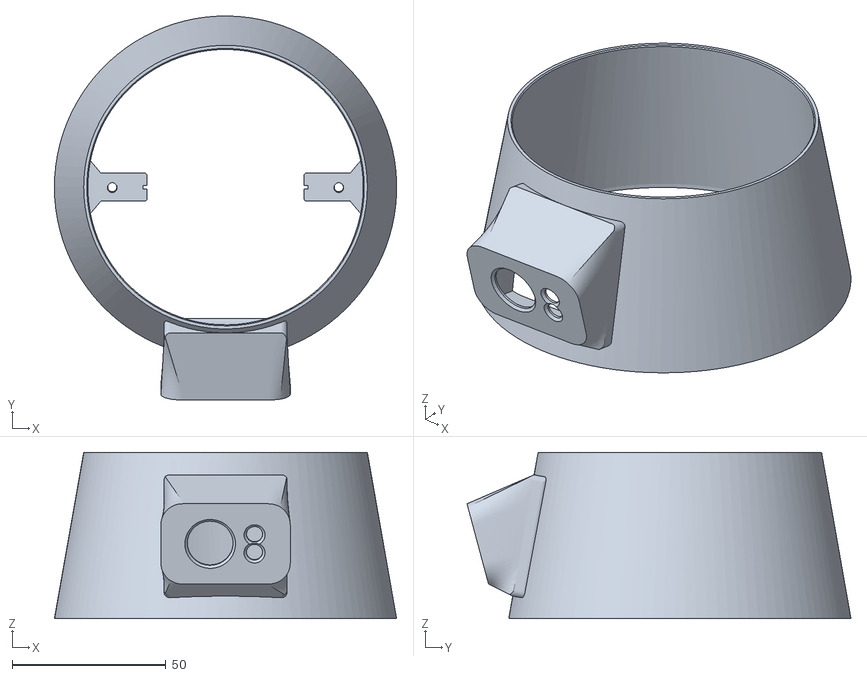
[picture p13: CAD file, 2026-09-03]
mechanical/stl/Buoy Mid Section.stl
111.2 x 124.7 x 54.0

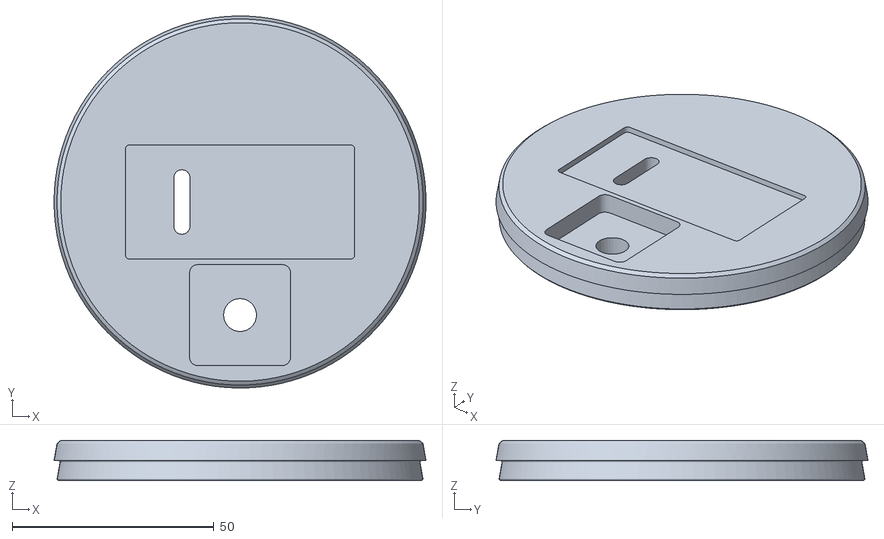
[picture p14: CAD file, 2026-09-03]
mechanical/stl/Buoy Top.stl
92.1 x 92.1 x 10.0

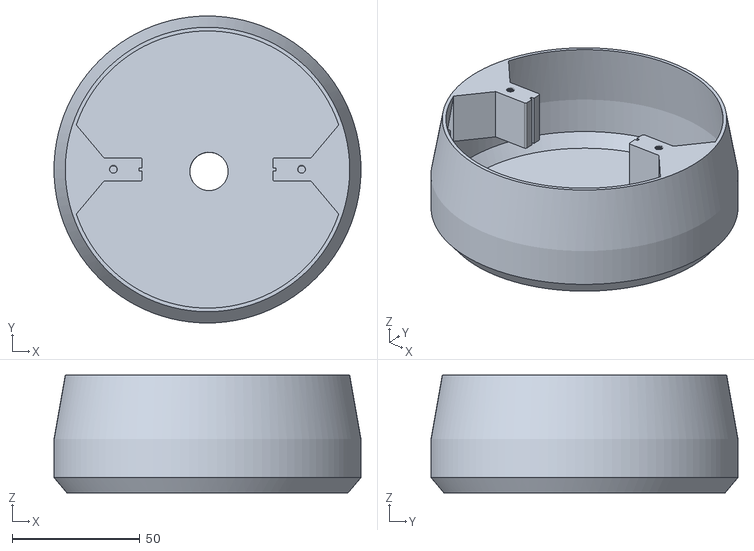
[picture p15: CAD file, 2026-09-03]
mechanical/stl/bottom half.stl
120.0 x 120.0 x 46.0

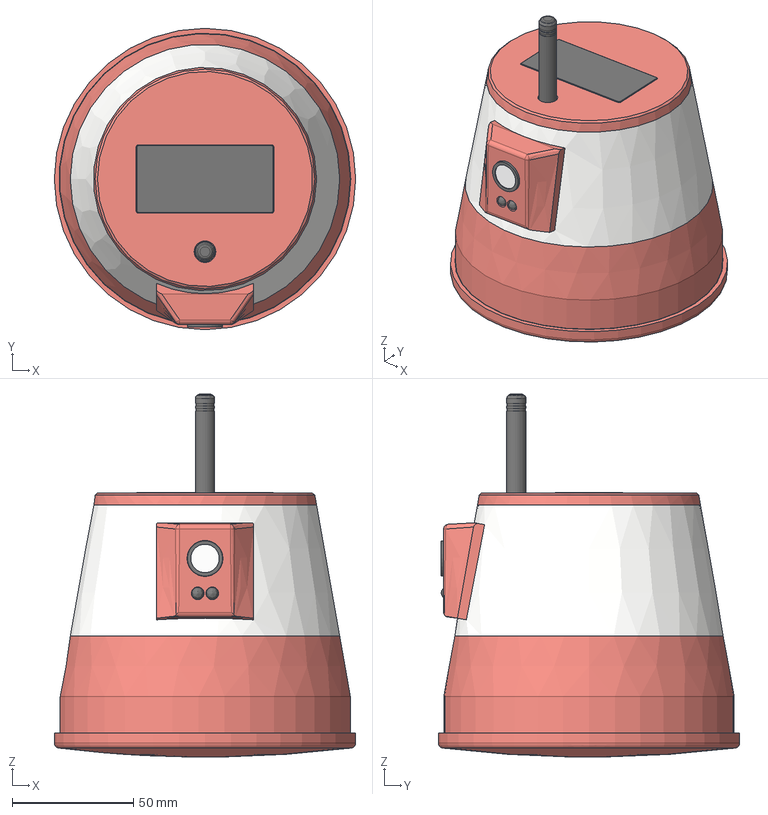
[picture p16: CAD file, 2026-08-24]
mechanical/stl/MarineSentinel.step
124.4 x 124.4 x 149.8 mm
Buoy Mid Section
PCB
trou1
trou002
trou003
trou004
trou005
trou006
trou007
trou008
Text_X
Symb_Y
Symb_X
Text_Y
Text_VCC
Text_GND
Text_SCL
Text_SDA
Text_XDA
Text_XCL
Text_ADO
Text_INT
R_0603_1608Metric
R_0603_1608Metric001
R_0603_1608Metric002
R_0603_1608Metric003
C_0603_1608Metric
C_0603_1608Metric001
C_0603_1608Metric002
C_0603_1608Metric003
Corps002
C_0603_1608Metric004
C_0603_1608Metric005
LED_0603_1608Metric_Castellated
QFN_16_1EP_4x4mm_P065mm_EP21x21mm
Text_ITGMPU
SOT_23_5
Corps001
Floating Base
Solar Panel
Document
Camera Unit

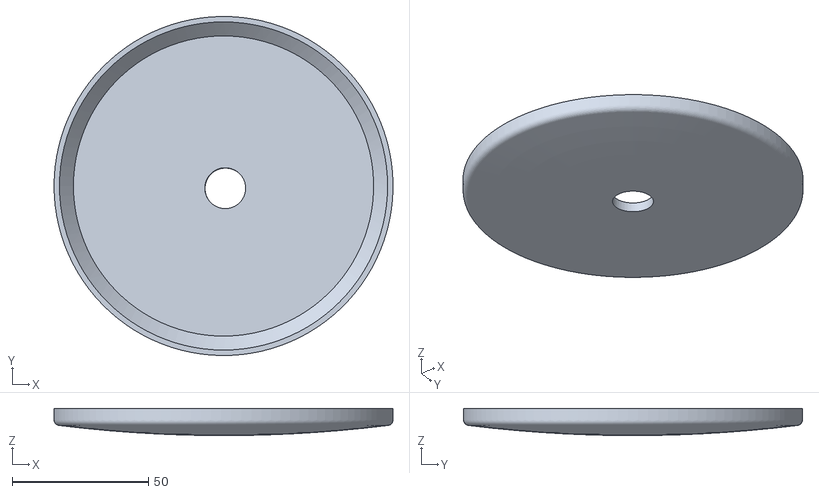
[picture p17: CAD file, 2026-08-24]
mechanical/stl/Floating Base.stl
124.4 x 124.4 x 9.92

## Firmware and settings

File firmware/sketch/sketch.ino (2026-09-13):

// SPDX-FileCopyrightText: Copyright (C) 2026 MarineSentinel Project
// SPDX-License-Identifier: MPL-2.0

#include <Arduino_RouterBridge.h>
#include <Arduino_LED_Matrix.h>
#include <OneWire.h>
#include <DallasTemperature.h>
#include <Wire.h>
#include <MPU6050_light.h>
#include <TinyGPSPlus.h>

// ── Pin assignments ───────────────────────────────────────────────────────────
#define TURBIDITY_PIN   A0   // Analog turbidity sensor (SEN0189 or equivalent)
#define DS18B20_PIN     D4   // DS18B20 1-Wire data line
// MPU6050 IMU — on the QWIIC connector, default address 0x68 (AD0 low).
// The board exposes three I2C buses (devicetree order: i2c2, i2c4, i2c3),
// mapped to Wire=I2C2 (digital pins D20/D21), Wire1=I2C4 (QWIIC connector),
// Wire2=I2C3 (analog pins A4/A5) — the QWIIC connector is Wire1, NOT the
// plain default Wire.
//
// GPS module — NMEA over the board's third hardware UART (Serial3).
// IMPORTANT: this is fixed to D20 (RX) / D21 (TX) by the board's devicetree
// pin muxing, NOT D11/D12 — D11/D12 (PB15/PB14) are plain GPIO/PWM pins with
// no UART peripheral behind them here, and this Zephyr core ships no
// SoftwareSerial to bit-bang one. Wire the module: GPS TX -> D20, GPS RX -> D21.
#define GPS_BAUD 9600

// ── Sensor driver objects ─────────────────────────────────────────────────────
OneWire           oneWire(DS18B20_PIN);
DallasTemperature tempSensor(&oneWire);
Arduino_LED_Matrix matrix;
MPU6050            imu(Wire1);   // Wire1 = I2C4 = the QWIIC connector
bool                imuReady = false;   // false if the MPU6050 didn't ACK on I2C at boot
byte                imuStatus = 255;    // imu.begin() return code, reported to Python for diagnostics
byte                imuScanAddr = 0;    // first address that ACKed a bus scan on failure, 0 = none
TinyGPSPlus         gps;

// ── Sampling configuration ────────────────────────────────────────────────────
const unsigned long SAMPLE_INTERVAL_MS   = 2000;   // 2 s between turbidity/temp readings
const unsigned long IMU_SEND_INTERVAL_MS = 100;    // 10 Hz orientation updates to the MPU
const unsigned long GPS_SEND_INTERVAL_MS = 1000;   // 1 Hz GPS updates to Python
const int           ADC_OVERSAMPLE       = 8;       // average N reads to reduce noise
unsigned long       lastSampleMs         = 0;
unsigned long       lastImuSendMs        = 0;
unsigned long       lastGpsSendMs        = 0;

// ── LED status helpers (UNO Q LEDs are active-low) ───────────────────────────
// LED3 (RGB, MCU-controllable): use Green = OK, Red = ALERT
inline void ledNormal()  { digitalWrite(LED3_R, HIGH); digitalWrite(LED3_G, LOW);  }
inline void ledAlert()   { digitalWrite(LED3_R, LOW);  digitalWrite(LED3_G, HIGH); }

// Scan the I2C bus for any responding device (used only to diagnose a failed
// MPU6050 init). Returns the first address that ACKs, or 0 if the bus is
// empty — 0 isn't a valid 7-bit I2C device address, so it's a safe sentinel.
byte scanI2CBus() {
  for (byte addr = 1; addr < 127; addr++) {
    Wire1.beginTransmission(addr);
    if (Wire1.endTransmission() == 0) return addr;
  }
  return 0;
}

// Bridge handler: Python sets alert state to light the red LED
void setAlert(bool active) {
  active ? ledAlert() : ledNormal();
  Serial.print("[MCU] Alert state -> ");
  Serial.println(active ? "ACTIVE" : "CLEAR");
}

void setup() {
  Serial.begin(115200);

  // Status LEDs
  pinMode(LED3_R, OUTPUT);
  pinMode(LED3_G, OUTPUT);
  ledNormal();

  // Turbidity analog input
  pinMode(TURBIDITY_PIN, INPUT);

  // DS18B20 — request 12-bit resolution (0.0625 °C steps, ~750 ms conversion)
  tempSensor.begin();
  tempSensor.setResolution(12);

  // MPU6050 — accel+gyro fused into roll/pitch, gyro-integrated yaw.
  // Mount the breakout flat with its silkscreen X-axis arrow pointing toward
  // the capsule's bow: then getAngleX()=roll (about bow/stern), getAngleY()=
  // pitch (nose up/down), getAngleZ()=yaw (heading, drifts — no magnetometer).
  Wire1.begin();   // QWIIC connector — see the Wire1/I2C4 note above
  imuStatus = imu.begin();
  if (imuStatus == 0) {
    Serial.println("[MCU] MPU6050 found — calibrating (keep capsule still)...");
    delay(1000);
    imu.calcOffsets(true, true);   // gyro + accelerometer offsets
    imuReady = true;
    Serial.println("[MCU] MPU6050 ready");
  } else {
    // Don't block the rest of the sensors on a missing/faulty IMU — just
    // skip orientation reporting, same fail-open approach as DS18B20 errors.
    Serial.print("[MCU] MPU6050 init failed, status=");
    Serial.println(imuStatus);
    imuScanAddr = scanI2CBus();
    Serial.print("[MCU] I2C bus scan — first device found at: 0x");
    Serial.println(imuScanAddr, HEX);
  }

  // LED matrix — show splash pattern then clear
  matrix.begin();
  matrix.clear();

  // GPS — Serial3 (fixed to D20/D21, see the pin-assignment note above)
  Serial3.begin(GPS_BAUD);

  // Router Bridge
  Bridge.begin();
  Bridge.provide("set_alert", setAlert);

  Serial.println("[MCU] MarineSentinel ready — sampling every 2 s");
}

void loop() {
  // Run the complementary filter every tick (not just every 2 s) so the
  // fused roll/pitch angles stay accurate — feeding it a large, coarse dt
  // would make the gyro-integration term dominate the fused result.
  if (imuReady) {
    imu.update();
  }

  unsigned long now = millis();

  if (now - lastImuSendMs >= IMU_SEND_INTERVAL_MS) {
    lastImuSendMs = now;
    if (imuReady) {
      Bridge.notify("imu_data", imu.getAngleX(), imu.getAngleY(), imu.getAngleZ());
    } else {
      // Keep reporting the failure once a second — a one-shot notify at boot
      // would race Python's Bridge.provide() registration (the MCU boots
      // and runs setup() well before the Python session is up) and could be
      // missed entirely. Repeating it guarantees Python sees it eventually.
      Bridge.notify("imu_status", imuStatus, imuScanAddr);
    }
  }

  // ── GPS: feed the NMEA parser on every loop tick, report at 1 Hz ─────────
  while (Serial3.available()) {
    gps.encode(Serial3.read());
  }

  if (now - lastGpsSendMs >= GPS_SEND_INTERVAL_MS) {
    lastGpsSendMs = now;
    bool fix = gps.location.isValid() && gps.location.age() < 5000;
    Bridge.notify("gps_data",
                   fix,
                   fix ? gps.location.lat() : 0.0,
                   fix ? gps.location.lng() : 0.0,
                   (fix && gps.speed.isValid())  ? gps.speed.kmph()  : 0.0,
                   (fix && gps.course.isValid()) ? gps.course.deg() : 0.0,
                   (int)gps.satellites.value());
  }

  if (now - lastSampleMs < SAMPLE_INTERVAL_MS) return;
  lastSampleMs = now;

  // ── Turbidity: oversample ADC and average ────────────────────────────────
  long rawSum = 0;
  for (int i = 0; i < ADC_OVERSAMPLE; i++) {
    rawSum += analogRead(TURBIDITY_PIN);
    delay(5);
  }
  int turbidityRaw = (int)(rawSum / ADC_OVERSAMPLE);

  // ── DS18B20 temperature ──────────────────────────────────────────────────
  tempSensor.requestTemperatures();
  float tempC = tempSensor.getTempCByIndex(0);

  // Log to serial (view with: arduino-app-cli monitor)
  Serial.print("[MCU] Turbidity raw=");
  Serial.print(turbidityRaw);
  Serial.print("  Temp=");
  Serial.print(tempC, 2);
  Serial.println(" C");

  // Stream readings up to Python — non-blocking fire-and-forget
  Bridge.notify("sensor_data", turbidityRaw, tempC);
}

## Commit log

2026-08-24 updated repo
    [Buoy Cover.stl, Buoy Mid Section.stl, Floating Base.stl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]
2026-09-03 updated stl files
    [Body6.stl, Buoy Cover.stl, Buoy Mid Section.stl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]
